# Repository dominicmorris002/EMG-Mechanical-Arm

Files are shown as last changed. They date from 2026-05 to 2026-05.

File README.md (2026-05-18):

# EMG Mechanical Arm

A myoelectric prosthetic arm that uses surface EMG signals to detect muscle gestures and drive a mechanical arm via a DC motor. The system consists of a **MyoWare 2.0 EMG sensor**, an **RP2040 microcontroller**, **DC motor driver H Bridge**, **Electrode Pads and Cable for Myoware Sensor**,  and a **DC motor** to control a 3D-printed mechanical arm.

---

## How It Works

The **RP2040** reads raw ADC values from the EMG sensor and uses the data to drive the H-Bridge to control the motor

---

## Repo Structure

```
EMG-Mechanical-Arm/
├── protomechanicalarm.py       # MicroPython code - Main product. Pre-tuned thresholds. Runs on RP2040 as main.py
├── learningarm.py              # MicroPython code - Optional. Adjusts thresholds automatically over time for better responsiveness
├── AITrainingCodeRP2040.py     # MicroPython code — runs on the RP2040 during AI data collection
├── AITrainingCodeComputer.py   # PC-side: collects data and trains the AI model
├── find_thresholds.py          # PC-side: finds ideal FLEX_ON / FLEX_OFF / FLEX_MAX thresholds
├── Doms PCB/                   # KiCad PCB design files
├── FinalPrint1/                # 3D print files (individual parts)
└── FULLPRINTFULLRightArm.3mf  # Full arm 3MF file for slicing
```

---

## Quickstart

You can choose to skip the AI thresholds and learning files as they work but are not needed for the product to run well. For the fastest and easiest approach plug in the PCB via USB to your computer.

1. **Download Thonny** and open `protomechanicalarm.py`
2. **Download MicroPython** onto the PCB through Thonny's interface at the bottom right — choose RP2040
3. **Save the file** by clicking File → Save As → MicroPython Device, and type `main.py`
4. The program will now always be stored on the chip and work as soon as plugged in

To change the trigger values of the sensor, simply change them in the code. The closer they are, the snappier they will be. Account for some amount of noise present. **14000 and 18000 are good starting numbers.**

---

## Optional: Learning Mode

If you want the arm to adapt and improve over time, use `learningarm.py` instead of `protomechanicalarm.py`. This version automatically adjusts the thresholds (`FLEX_ON`, `FLEX_OFF`, `FLEX_MAX`) based on your muscle signals during use. It learns from each flex/relax cycle and gets more responsive and personalized over time.

### How Learning Mode Works

- Tracks the peak muscle signal from each flex cycle
- Recalculates thresholds after each use based on a history of your last 10 peak signals
- Keeps thresholds within safe limits to prevent drift
- Prints threshold updates to the console so you can monitor adaptation

### When to Use Learning Mode

- You want the arm to automatically personalize to your muscle patterns
- You prefer not to manually tune threshold values
- You want the system to adapt to day-to-day variations in your signal

## Advanced: AI Training Mode

The AI training mode uses a Python script on your computer to collect muscle data and calculate optimal thresholds for you. This is optional and requires running Python scripts alongside the RP2040 code.

### Step 1 — Flash the RP2040 for Data Collection

Copy `AITrainingCodeRP2040.py` to your RP2040 as `main.py` using Thonny or `mpremote`. This streams raw ADC values over USB serial.

```python
# AITrainingCodeRP2040.py — runs on the RP2040
from machine import ADC, Pin
import time

adc = ADC(Pin(27))  # GP27 = ADC1

while True:
    val = adc.read_u16()  # 0–65535
    print(val)
    time.sleep_ms(1)      # ~1000 samples/sec
```

> **Important:** Close Thonny before running the PC training scripts. Both cannot hold the serial port at the same time.

---

### Step 2 — Install PC Dependencies

```bash
pip install numpy scipy pyserial tensorflow
```

---

### Step 3 — Collect EMG Data

```bash
python find_thresholds.py collect --label rest --port COM5 --seconds 20
python find_thresholds.py collect --label flex --port COM5 --seconds 20
```

Replace `COM5` with your actual serial port (`/dev/ttyACM0` on Linux/Mac).

---

### Step 4 — Process Windows

```bash
python find_thresholds.py windows
```

---

### Step 5 — Find Your Thresholds

```bash
python find_thresholds.py train_thresholds
```

This prints your personal `FLEX_ON`, `FLEX_OFF`, and `FLEX_MAX` values. Copy these into your motor control code on the RP2040.

---

## Bill of Materials (BOM)

> Costs omitted — use this as a copy-paste parts list for sourcing.

| Component | Description | Qty | Source / Part # |
|---|---|---|---|
| DC Motor | 12V High Torque Turbine Worm Geared Motor, 200 RPM, 8mm shaft | 1 | MECCANIXITY |
| Motor Driver | L298N Dual H-Bridge Motor Driver | 1 | Generic |
| EMG Sensor | MyoWare 2.0 compatible sensor cable | 1 | MyoWare |
| Electrode Pads | EMG Surface Electrodes, 6-pack | 3 packs | DigiKey #1528-2172-ND (Mfg #2773) |
| Microcontroller | RP2040 + PCB | 1 | Custom PCB via JLCPCB |
| Power Supply | 12V DC (5A) + 5V DC dual output power bank | 1 | ColdBye Dual Source Power Bank 12V and 5V |
| Enclosure | Custom 3D-printed enclosure | 1 | Print files in repo |
| Straps | Adjustable straps for arm attachment | 2 | Generic |
| Bearing (small) | 0.315" ID × 0.866" OD × 0.276" W | 15 | DigiKey #1995-1010-ND (Mfg #608-2RS-W/CHEVRONSRI2) |
| Bearing (large) | 0.591" ID × 1.26" OD × 0.354" W | 5 | DigiKey #1995-1014-ND (Mfg #6002ZZ) |
| Thread Inserts | 0.28" Dia × 0.38" H heat-set inserts | 50 | DigiKey #5519-HI-132-WH-ND (Mfg #HI-132-WH) |
| Machine Screws | Pan Phillips #10-32 | 50 | DigiKey #36-9909-ND (Mfg #9909) |
| Switches | SPST-NO 0.001A 5V detect switch | 50 | DigiKey #450-3349-ND (Mfg #JJOV0UL650NONPRBK) |
| PCBs | Custom arm PCBs assembled by JLCPCB | 1 | JLCPCB |
| Miscellaneous | Wires, breadboard, connectors | — | Generic |

---

## Hardware Notes

- EMG sensor connects to **GP27 (ADC1)** on the RP2040
- Motor driver IN1/IN2 pins connect to RP2040 GPIO outputs
- 12V powers the motor; RP2040 runs on 3.3V/5V USB — do not cross-connect
- Electrode placement: two signal electrodes along the muscle belly, one reference on a bony landmark (e.g., elbow)

---

## 3D Printing

The full arm model is included as `FULLPRINTFULLRightArm.3mf`. Individual parts are in the `FinalPrint1/` folder. Recommended print settings: H2D Printer Size with PLA Component.

---

## Project Gallery

<div align="center">

https://github.com/user-attachments/assets/b0d67ed7-32eb-4f09-bf58-b973187cbe4e

</div>

<div align="center">

Arm Assembly

</div>

<div align="center">

Full Arm Design

</div>

<div align="center">

Mechanical Detail

</div>

<div align="center">

Circuit Diagram

</div>

<div align="center">

System Overview

</div>

---

## License

### Custom License — EMG Mechanical Arm

**Copyright © 2026 Dominic Morris** — All Rights Reserved (unless specified below)

This project is shared under a **modified open-source license** with the following terms:

#### Permitted Uses:
- **Personal & Educational Use:** You may freely use, study, modify, and build upon this work for personal, non-commercial, and educational purposes.
- **Open Source Contributions:** You may fork, modify, and improve this project for non-commercial use.

#### Requirements:
- **Attribution Required:** You must credit Dominic Morris and link to this repository in any public use, distribution, or derived work.
- **Share Modifications:** Any modifications, improvements, or derivative works must be publicly shared (open-sourced) and made available to the community with attribution.
- **No Commercial Resale Without Permission:** You may NOT sell, commercialize, or profit from this work or any derivative without explicit written permission and a commercial licensing agreement.

#### Commercial Use:
- If you wish to commercialize this work (sell it as a product, include it in a commercial offering, or generate profit):
  1. You **must obtain explicit written permission** from Dominic Morris
  2. Dominic Morris **must receive credit** as the original creator
  3. Dominic Morris **must receive a fair share of profit** (terms to be negotiated)
  4. A formal licensing agreement must be established before commercialization

#### Disclaimer:
THIS PROJECT IS PROVIDED "AS IS" WITHOUT WARRANTY OF ANY KIND, EXPRESS OR IMPLIED. THE AUTHOR IS NOT LIABLE FOR ANY DAMAGES, INJURIES, OR LOSSES RESULTING FROM USE OF THIS PROJECT.

---

**For inquiries regarding commercial licensing, collaborations, or permission requests, please contact Dominic Morris.**

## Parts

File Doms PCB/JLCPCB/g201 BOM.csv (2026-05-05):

Reference | Value | Datasheet | Footprint | Qty | DNP
C1,C2,C9 | 100nF |  | Capacitor_SMD:C_0805_2012Metric | 3
C3,C5 | 15pF |  | Capacitor_SMD:C_0805_2012Metric | 2
C4,C6,C7,C8 | 10uF |  | Capacitor_SMD:C_0805_2012Metric | 4
D1 | D_Schottky_Small |  | Diode_SMD:D_SMA | 1
D2,D3,D4,D5 | LED |  | LED_SMD:LED_0805_2012Metric | 4
GPIOS1,H-Bridge1,H-Bridge2 | Conn_01x10 |  | Connector_PinHeader_2.54mm:PinHeader_1x10_P2.54mm_Vertical | 3
J1 | USB_C_Receptacle_USB2.0_16P | https://www.usb.org/sites/default/files/documents/usb_type-c.zip | Connector_USB:USB_C_Receptacle_HRO_TYPE-C-31-M-12 | 1
J2 | Conn_01x03 |  | Connector_PinSocket_2.54mm:PinSocket_1x03_P2.54mm_Vertical | 1
J3 | Conn_01x04 |  | Connector_PinSocket_2.54mm:PinSocket_1x04_P2.54mm_Vertical | 1
MyowareSensors1 | Conn_01x06 |  | Connector_PinHeader_2.54mm:PinHeader_1x06_P2.54mm_Vertical | 1
R1,R9,R10,R13,R14,R15 | 1k |  | Resistor_SMD:R_0805_2012Metric | 6
R2,R7 | 10k |  | Resistor_SMD:R_0805_2012Metric | 2
R3,R4 | 27 |  | Resistor_SMD:R_0805_2012Metric | 2
R5,R6 | 5.1K |  | Resistor_SMD:R_0805_2012Metric | 2
R8 | 100 |  | Resistor_SMD:R_0805_2012Metric | 1
R11,R12 | 4.7k |  | Resistor_SMD:R_0805_2012Metric | 2
R16 | 50 |  | Resistor_SMD:R_0805_2012Metric | 1
SW1 | SW_SPST |  | Button_Switch_SMD:SW_SPST_CK_RS282G05A3 | 1
U1 | W25Q32JVSS | http://www.winbond.com/resource-files/w25q32jv%20revg%2003272018%20plus.pdf | Package_SO:SOIC-8_5.23x5.23mm_P1.27mm | 1
U2 | AMS1117-3.3 | http://www.advanced-monolithic.com/pdf/ds1117.pdf | Package_TO_SOT_SMD:SOT-223-3_TabPin2 | 1
U3 | RP2040 | https://datasheets.raspberrypi.com/rp2040/rp2040-datasheet.pdf | Package_DFN_QFN:QFN-56-1EP_7x7mm_P0.4mm_EP3.2x3.2mm | 1
Y1 | 12Mhz |  | Crystal:Crystal_SMD_SeikoEpson_FA238V-4Pin_3.2x2.5mm | 1

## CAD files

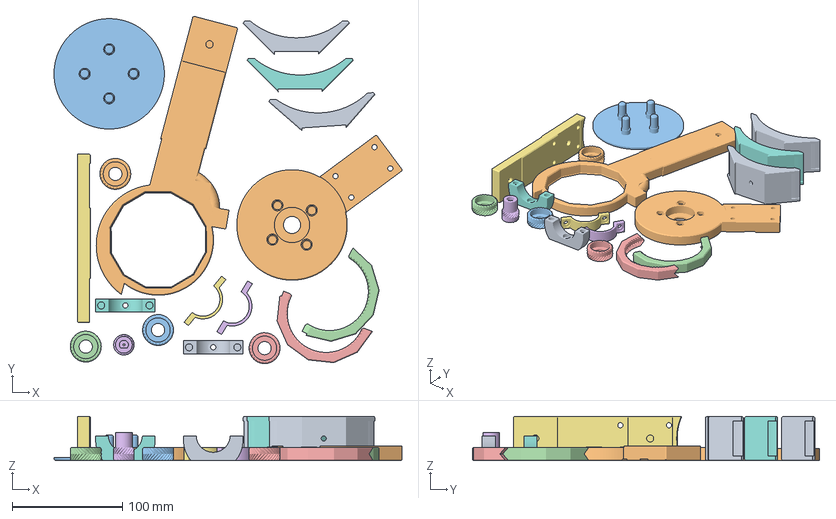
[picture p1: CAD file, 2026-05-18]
FULLPRINTFULLRightArm.3mf
315.3 x 314.7 x 40.0 mm
armBracket2.stl x 3
UpperArmT.stl
coverPlate.stl
prOutside.stl x 2
motorClampUpper.stl x 2
motorClampLower.stl x 2
planetGear.stl x 4
prSunGear.stl
upperArmB2.stl
Assembly_B_B

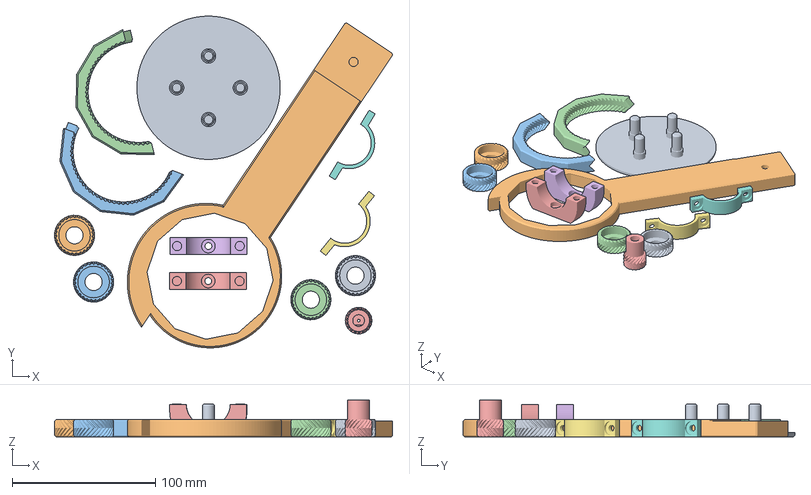
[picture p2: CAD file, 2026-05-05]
FinalPrint1/fullPlatePrintPart1.3mf
235.9 x 231.6 x 25.5 mm
coverPlate.stl
lowerArm.stl
prOutside.stl x 2
motorClampLower.stl x 2
motorClampUpper.stl x 2
planetGear.stl x 4
prSunGear.stl

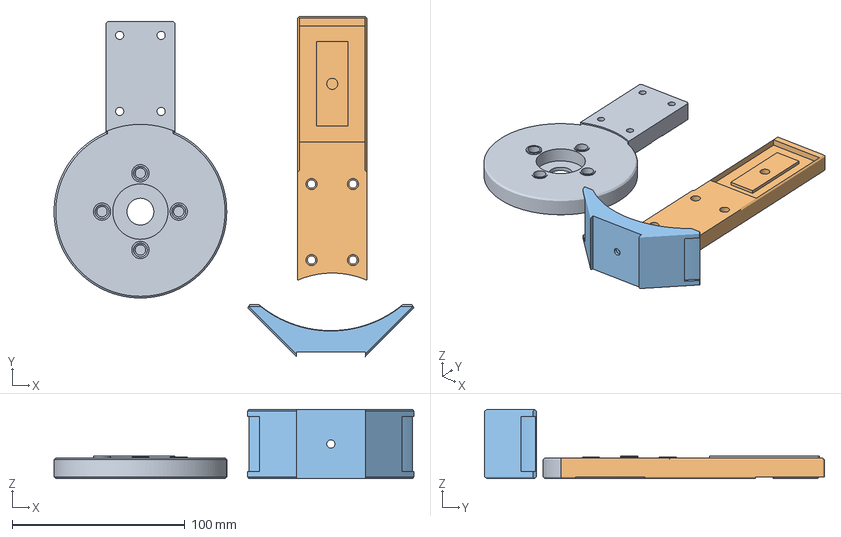
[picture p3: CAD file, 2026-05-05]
FinalPrint1/fullPlatePrintPart2.3mf
208.3 x 196.8 x 40.0 mm
UpperArmT.stl
upperArmB2.stl
armBracket2.stl

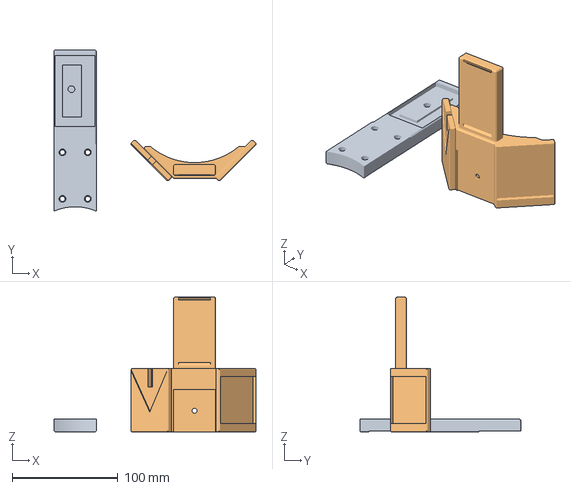
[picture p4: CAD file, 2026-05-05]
FinalPrint1/coverPlate.3mf
191.1 x 152.6 x 127.5 mm
upperArmB2.stl
customBracket.stl

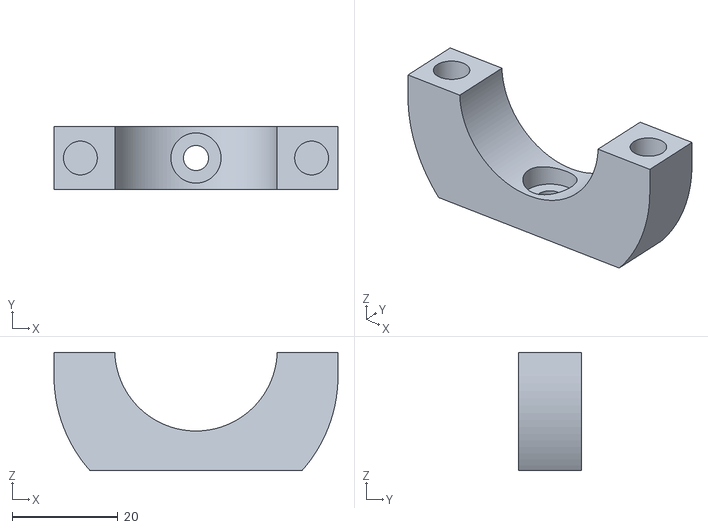
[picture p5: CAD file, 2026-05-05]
FinalPrint1/motorClampLower.stl
53.8 x 12.0 x 22.4

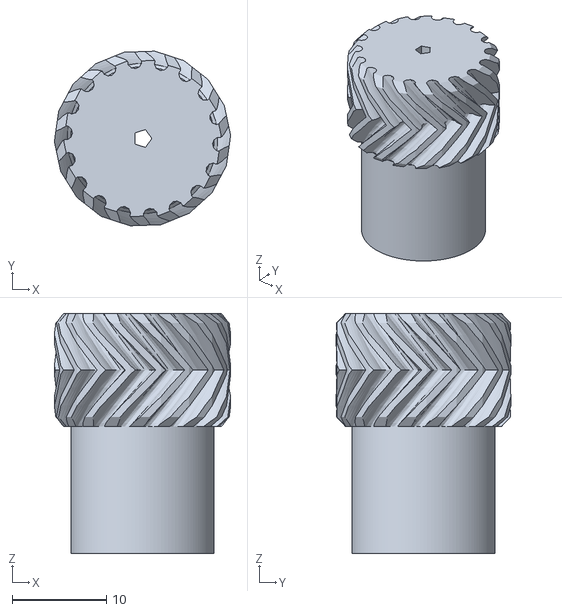
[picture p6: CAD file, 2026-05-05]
FinalPrint1/prSunGear.stl
18.7 x 18.6 x 25.5

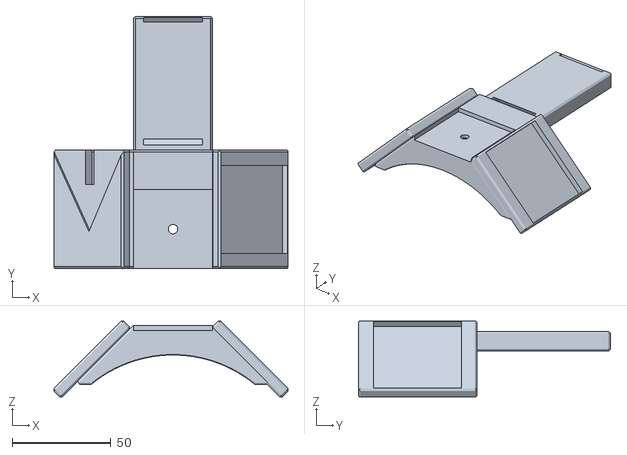
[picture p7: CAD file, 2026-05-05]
FinalPrint1/customBracket.stl
118.2 x 127.5 x 38.2

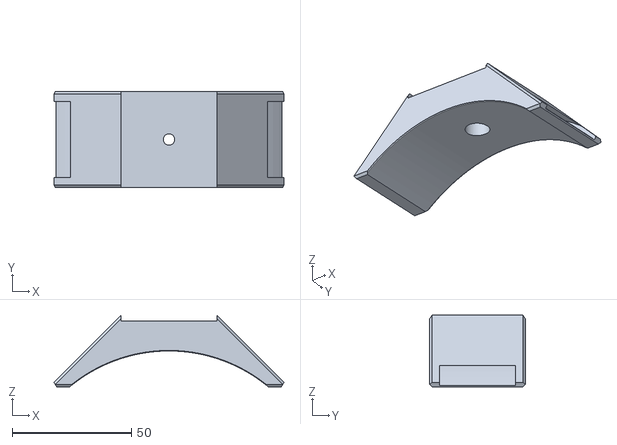
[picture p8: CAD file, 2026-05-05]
FinalPrint1/armBracket2.stl
96.2 x 40.0 x 30.0

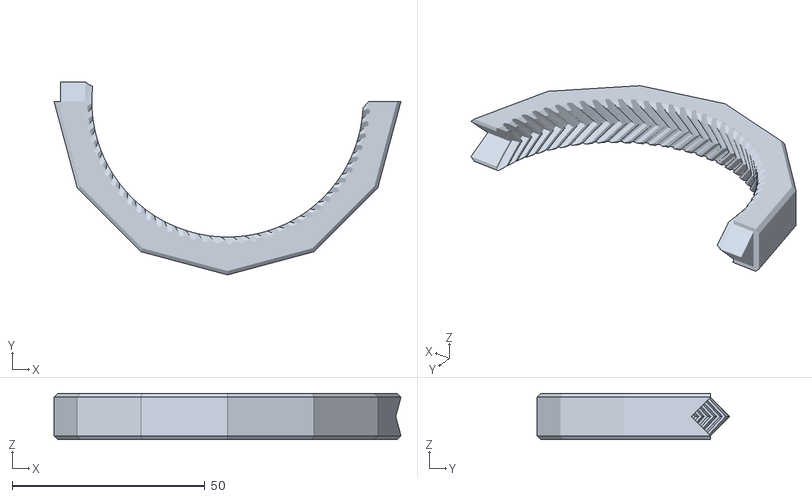
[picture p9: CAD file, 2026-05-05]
FinalPrint1/prOutside.stl
90.0 x 50.0 x 12.0

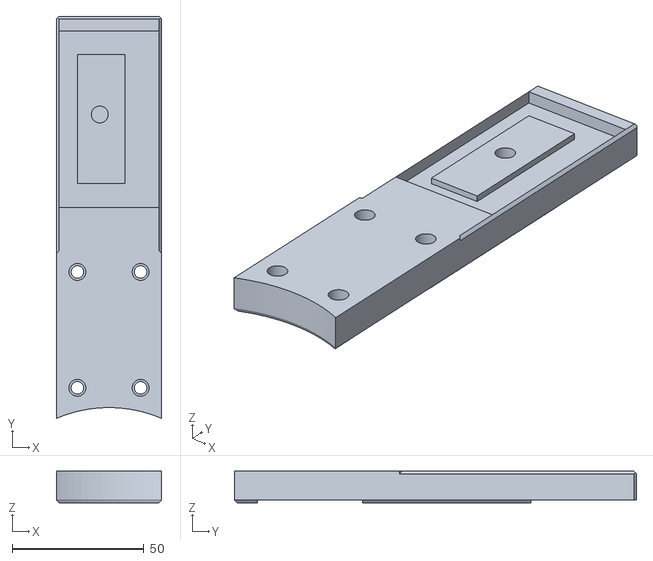
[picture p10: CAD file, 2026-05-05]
FinalPrint1/upperArmB2.stl
40.0 x 152.6 x 12.0

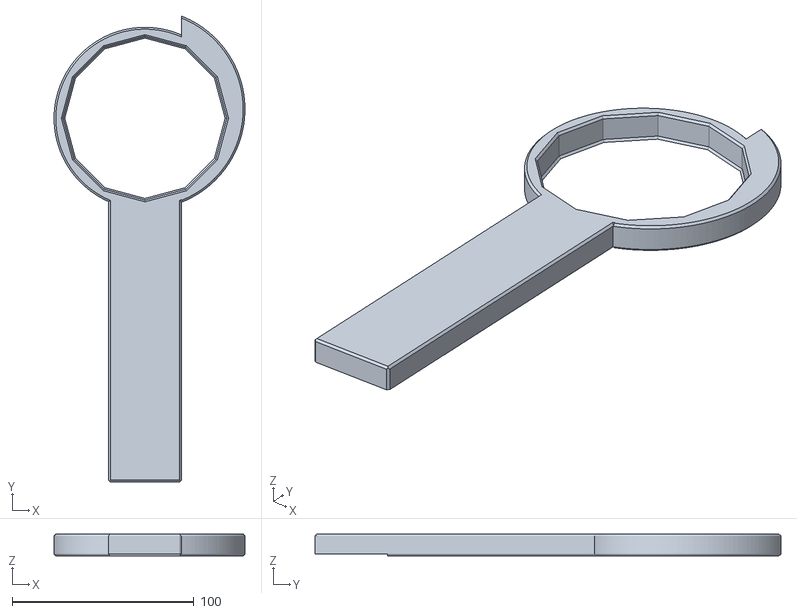
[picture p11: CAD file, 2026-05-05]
FinalPrint1/lowerArm.stl
105.0 x 256.2 x 12.0

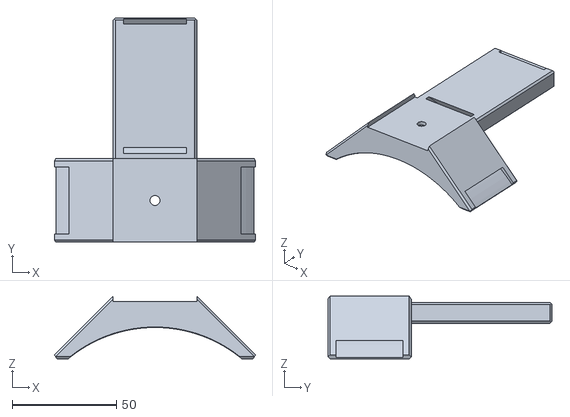
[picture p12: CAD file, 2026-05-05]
FinalPrint1/strapSupporBatt.stl
96.2 x 107.5 x 30.0

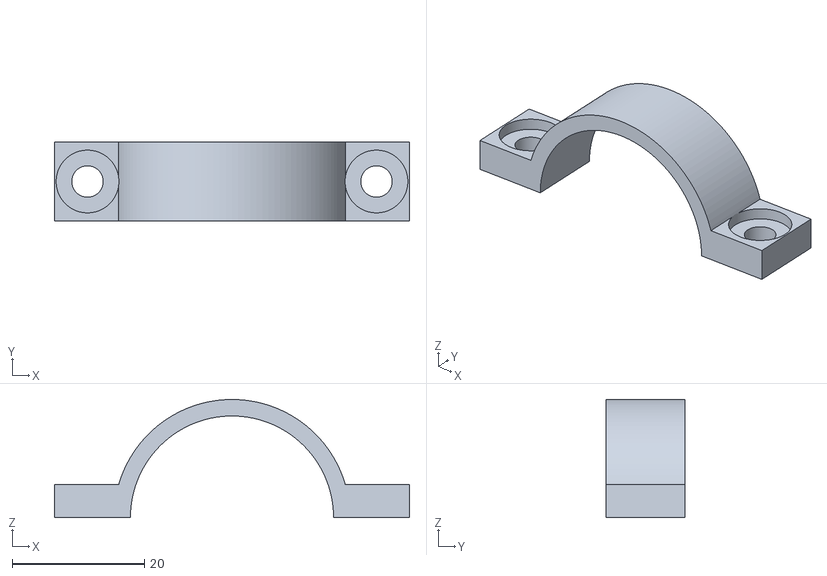
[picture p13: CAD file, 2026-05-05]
FinalPrint1/motorClampUpper.stl
53.8 x 12.0 x 17.9

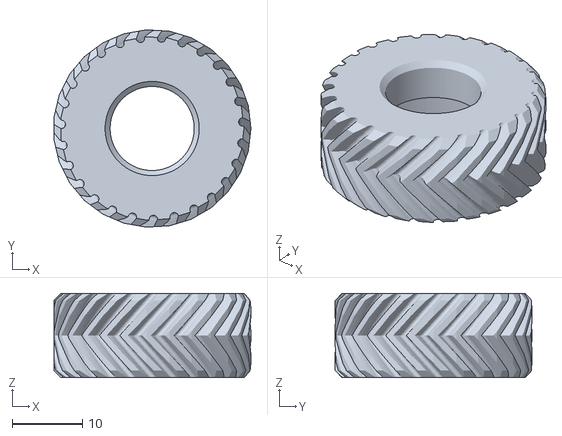
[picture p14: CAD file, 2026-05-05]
FinalPrint1/planetGear.stl
28.0 x 28.1 x 12.0

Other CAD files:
FinalPrint1/meshCover.stl
FinalPrint1/UpperArmT.stl
FinalPrint1/coverPlate.stl

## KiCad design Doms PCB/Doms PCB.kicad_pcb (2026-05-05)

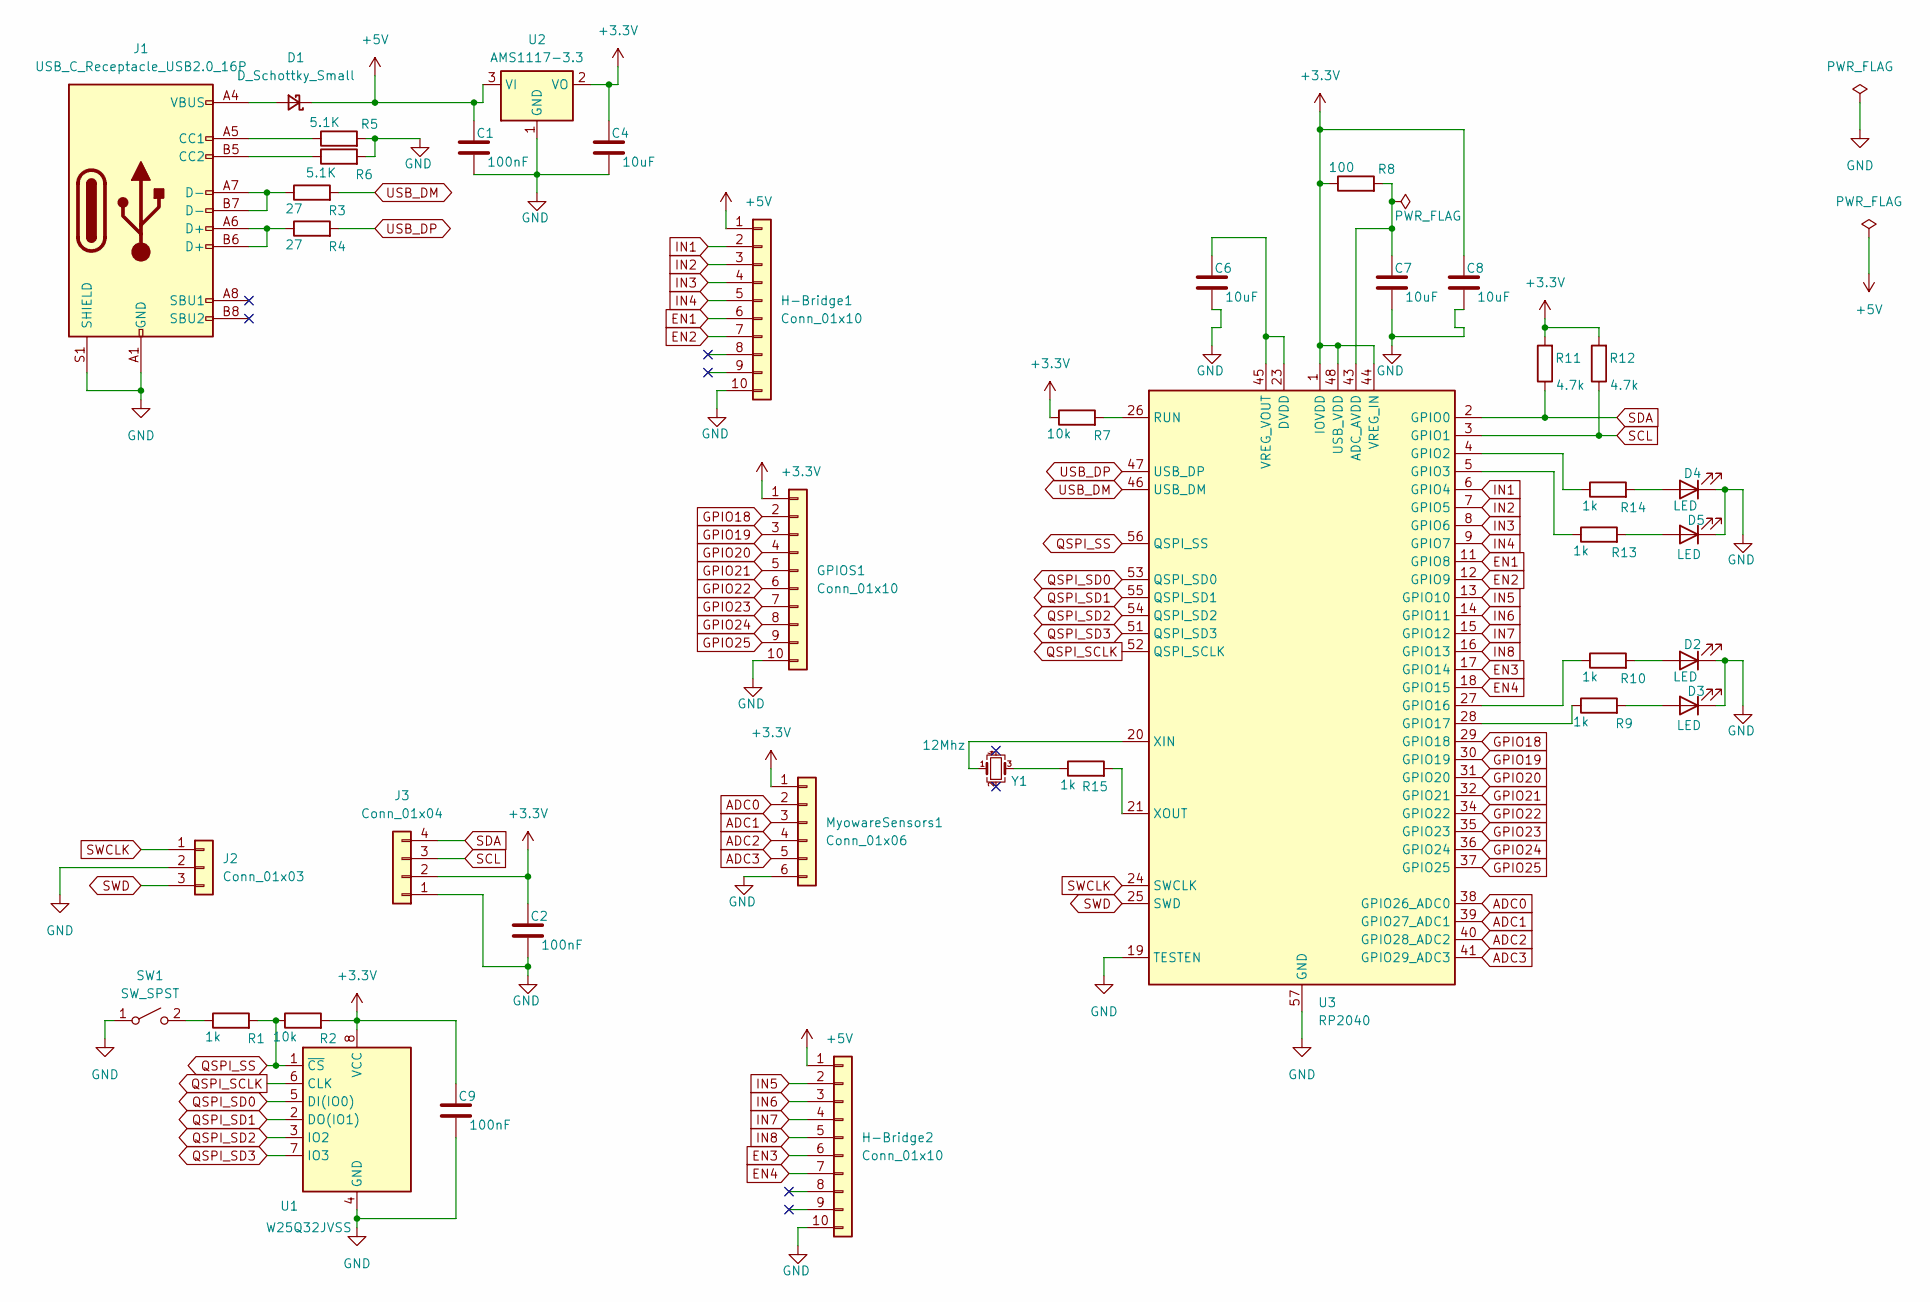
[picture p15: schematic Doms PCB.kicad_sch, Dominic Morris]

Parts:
C1, C2, C9: 100nF; C_0805_2012Metric
C4, C6, C7, C8: 10uF; C_0805_2012Metric
D1: D_Schottky_Small; D_SMA
D2, D3, D4, D5: LED; LED_0805_2012Metric
GPIOS1: Conn_01x10; PinHeader_1x10_P2.54mm_Vertical
H-Bridge1, H-Bridge2: Conn_01x10; PinHeader_1x10_P2.54mm_Vertical
J1: USB_C_Receptacle_USB2.0_16P; USB_C_Receptacle_HRO_TYPE-C-31-M-12
J2: Conn_01x03; PinSocket_1x03_P2.54mm_Vertical
J3: Conn_01x04; PinSocket_1x04_P2.54mm_Vertical
MyowareSensors1: Conn_01x06; PinHeader_1x06_P2.54mm_Vertical
R1, R9, R10, R13, R14, R15: 1k; R_0805_2012Metric
R2, R7: 10k; R_0805_2012Metric
R3, R4: 27; R_0805_2012Metric
R5, R6: 5.1K; R_0805_2012Metric
R8: 100; R_0805_2012Metric
R11, R12: 4.7k; R_0805_2012Metric
SW1: SW_SPST; SW_SPST_CK_RS282G05A3
U1: W25Q32JVSS; SOIC-8_5.23x5.23mm_P1.27mm
U2: AMS1117-3.3; SOT-223-3_TabPin2
U3: RP2040; QFN-56-1EP_7x7mm_P0.4mm_EP3.2x3.2mm
Y1: 12Mhz; Crystal_SMD_SeikoEpson_FA238V-4Pin_3.2x2.5mm

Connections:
+3.3V: C2.1, C4.1, C8.1, C9.1, GPIOS1.1, J3.2, MyowareSensors1.1, R2.2, R7.1, R8.1, R11.2, R12.2, U1.8 (VCC), U2.2 (VO), U3.1 (IOVDD), U3.10 (IOVDD), U3.22 (IOVDD), U3.33 (IOVDD), U3.42 (IOVDD), U3.44 (VREG_IN), U3.48 (USB_VDD), U3.49 (IOVDD)
+5V: C1.1, D1.1 (K), H-Bridge1.1, H-Bridge2.1, U2.3 (VI)
ADC0: MyowareSensors1.2, U3.38 (GPIO26_ADC0)
ADC1: MyowareSensors1.3, U3.39 (GPIO27_ADC1)
ADC2: MyowareSensors1.4, U3.40 (GPIO28_ADC2)
ADC3: MyowareSensors1.5, U3.41 (GPIO29_ADC3)
EN1: H-Bridge1.6, U3.11 (GPIO8)
EN2: H-Bridge1.7, U3.12 (GPIO9)
EN3: H-Bridge2.6, U3.17 (GPIO14)
EN4: H-Bridge2.7, U3.18 (GPIO15)
GND: C1.2, C2.2, C4.2, C6.2, C7.2, C8.2, C9.2, D2.1 (K), D3.1 (K), D4.1 (K), D5.1 (K), GPIOS1.10, H-Bridge1.10, H-Bridge2.10, J1.A1 (GND), J1.A12 (GND), J1.B1 (GND), J1.B12 (GND), J1.S1 (SHIELD), J2.2, J3.1, MyowareSensors1.6, R5.2, R6.2, SW1.1 (A), U1.4 (GND), U2.1 (GND), U3.19 (TESTEN), U3.57 (GND)
GPIO18: GPIOS1.2, U3.29 (GPIO18)
GPIO19: GPIOS1.3, U3.30 (GPIO19)
GPIO20: GPIOS1.4, U3.31 (GPIO20)
GPIO21: GPIOS1.5, U3.32 (GPIO21)
GPIO22: GPIOS1.6, U3.34 (GPIO22)
GPIO23: GPIOS1.7, U3.35 (GPIO23)
GPIO24: GPIOS1.8, U3.36 (GPIO24)
GPIO25: GPIOS1.9, U3.37 (GPIO25)
IN1: H-Bridge1.2, U3.6 (GPIO4)
IN2: H-Bridge1.3, U3.7 (GPIO5)
IN3: H-Bridge1.4, U3.8 (GPIO6)
IN4: H-Bridge1.5, U3.9 (GPIO7)
IN5: H-Bridge2.2, U3.13 (GPIO10)
IN6: H-Bridge2.3, U3.14 (GPIO11)
IN7: H-Bridge2.4, U3.15 (GPIO12)
IN8: H-Bridge2.5, U3.16 (GPIO13)
unnamed: D1.2 (A), J1.A4 (VBUS), J1.A9 (VBUS), J1.B4 (VBUS), J1.B9 (VBUS)
unnamed: D2.2 (A), R10.2
unnamed: D3.2 (A), R9.2
unnamed: D4.2 (A), R14.2
unnamed: D5.2 (A), R13.2
unnamed: J1.A5 (CC1), R5.1
unnamed: J1.B5 (CC2), R6.1
unnamed: J1.A6 (D+), J1.B6 (D+), R4.1
unnamed: J1.A7 (D-), J1.B7 (D-), R3.1
unnamed: R15.1, Y1.3
unnamed: R1.1, SW1.2 (B)
unnamed: C7.1, R8.2, U3.43 (ADC_AVDD)
unnamed: R14.1, U3.4 (GPIO2)
unnamed: R13.1, U3.5 (GPIO3)
unnamed: R10.1, U3.27 (GPIO16)
unnamed: R9.1, U3.28 (GPIO17)
unnamed: R7.2, U3.26 (RUN)
unnamed: C6.1, U3.23 (DVDD), U3.45 (VREG_VOUT), U3.50 (DVDD)
unnamed: U3.20 (XIN), Y1.1
unnamed: R15.2, U3.21 (XOUT)
QSPI_SCLK: U1.6 (CLK), U3.52 (QSPI_SCLK)
QSPI_SD0: U1.5 (DI(IO0)), U3.53 (QSPI_SD0)
QSPI_SD1: U1.2 (DO(IO1)), U3.55 (QSPI_SD1)
QSPI_SD2: U1.3 (IO2), U3.54 (QSPI_SD2)
QSPI_SD3: U1.7 (IO3), U3.51 (QSPI_SD3)
QSPI_SS: R1.2, R2.1, U1.1 (~CS), U3.56 (QSPI_SS)
SCL: J3.3, R12.1, U3.3 (GPIO1)
SDA: J3.4, R11.1, U3.2 (GPIO0)
SWCLK: J2.1, U3.24 (SWCLK)
SWD: J2.3, U3.25 (SWD)
USB_DM: R3.2, U3.46 (USB_DM)
USB_DP: R4.2, U3.47 (USB_DP)

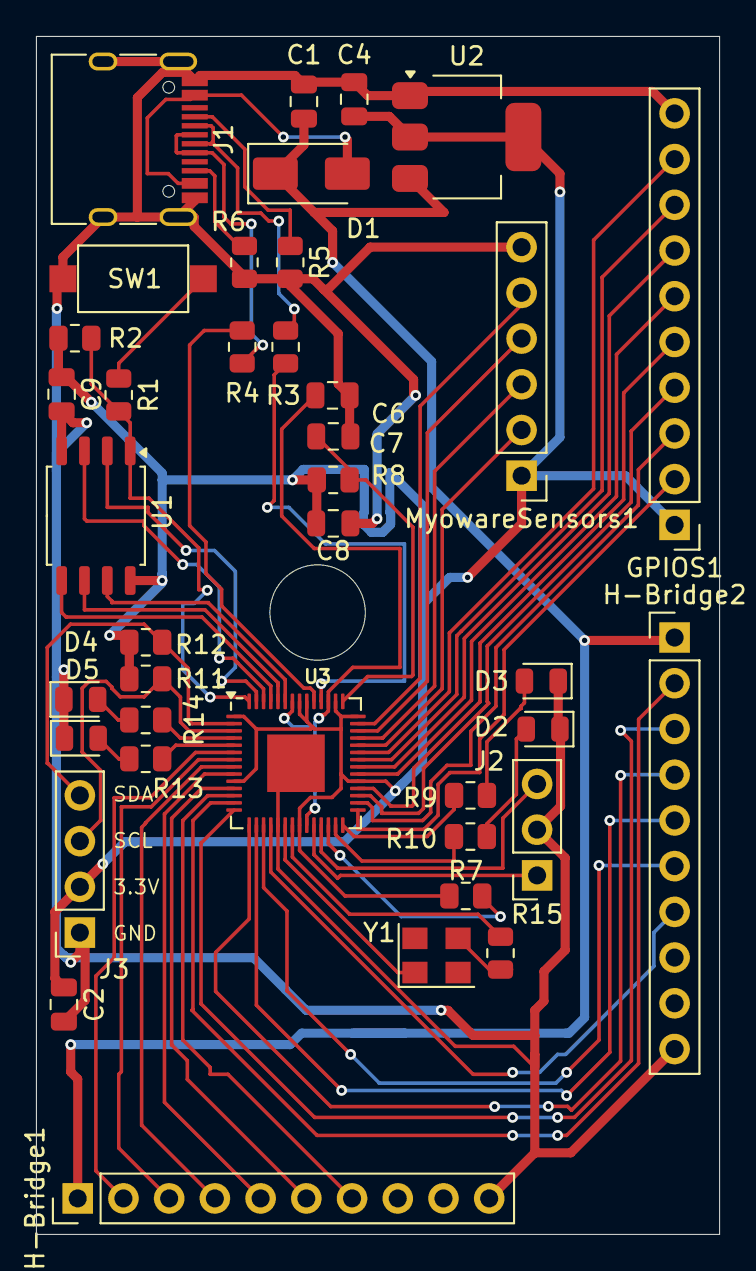
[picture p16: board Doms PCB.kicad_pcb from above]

Board: 2 copper layers, 38.0 x 66.6 mm, 39 parts (0 on the bottom side), 59 nets.

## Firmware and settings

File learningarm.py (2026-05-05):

from machine import Pin, ADC, PWM
import time

# --- Sensor ---
adc = ADC(Pin(27))

# --- H-Bridge pins ---
in1 = Pin(4, Pin.OUT); in2 = Pin(5, Pin.OUT)
en1 = PWM(Pin(8)); en1.freq(20000)

# --- LEDs ---
leds = [Pin(2, Pin.OUT), Pin(3, Pin.OUT), Pin(16, Pin.OUT), Pin(17, Pin.OUT)]

# --- Motor ---
def motor_forward(speed):
    in1.value(1); in2.value(0)
    en1.duty_u16(int(65535 * speed))
def motor_reverse(speed):
    in1.value(0); in2.value(1)
    en1.duty_u16(int(65535 * speed))
def motor_stop():
    in1.value(0); in2.value(0)
    en1.duty_u16(0)

# --- Rolling average ---
WINDOW = 20
readings = [0] * WINDOW
read_idx = 0
def smoothed_read():
    global read_idx
    val = adc.read_u16()
    readings[read_idx] = val
    read_idx = (read_idx + 1) % WINDOW
    return sum(readings) // WINDOW

# ============================================================
# --- Adaptive Smart Thresholds ---
# Tuned for: resting signal ~14500, peaks hitting 65535
#
# Signal zones:
#   ~14500  = fully relaxed (idle)
#   15200   = FLEX_OFF — just above idle, easy to drop below when relaxing
#   20971   = FLEX_ON  — clear activation point
#   60000+  = full flex
# ============================================================
FLEX_ON  = 20000
FLEX_OFF = 15200   # tight above idle ~14500 — relaxing easily clears this
FLEX_MAX = 60000

MIN_SPEED = 0.15
MAX_SPEED = 0.90

# Adaptive ratios
ON_RATIO       = 0.32
OFF_RATIO      = 0.24   # tracks just above idle fraction of avg peak
MAX_LEARN_RATE = 0.10

# Peak history
PEAK_HISTORY  = 10
best_peak     = FLEX_MAX
session_peaks = []

# Clamp limits — OFF kept tight above idle band
FLEX_ON_MIN  = 17000; FLEX_ON_MAX  = 40000
FLEX_OFF_MIN = 14800; FLEX_OFF_MAX = 18000  # never stray far from idle+700
FLEX_MAX_MIN = 40000; FLEX_MAX_MAX = 65000

flex_peak_this_rep = 0

def update_adaptive_thresholds(peak):
    global FLEX_ON, FLEX_OFF, FLEX_MAX, best_peak, session_peaks

    if peak < FLEX_ON:
        return  # ignore junk reps

    if peak > best_peak:
        best_peak = peak
        print("[Adaptive] New best peak: {}".format(best_peak))

    session_peaks.append(peak)
    if len(session_peaks) > PEAK_HISTORY:
        session_peaks.pop(0)

    avg_peak = sum(session_peaks) // len(session_peaks)

    new_on  = int(avg_peak * ON_RATIO)
    new_off = int(avg_peak * OFF_RATIO)
    new_max = int(FLEX_MAX + MAX_LEARN_RATE * (best_peak - FLEX_MAX))

    FLEX_ON  = max(FLEX_ON_MIN,  min(new_on,  FLEX_ON_MAX))
    FLEX_OFF = max(FLEX_OFF_MIN, min(new_off, FLEX_OFF_MAX))
    FLEX_MAX = max(FLEX_MAX_MIN, min(new_max, FLEX_MAX_MAX))

    # Enforce gap: OFF must always be below ON with room to spare
    if FLEX_OFF >= FLEX_ON - 2000:
        FLEX_OFF = FLEX_ON - 2500

    print("[Adaptive] ON:{} OFF:{} MAX:{} (avg_peak:{} best:{})".format(
        FLEX_ON, FLEX_OFF, FLEX_MAX, avg_peak, best_peak))

# ============================================================

# --- Timing ---
DEBOUNCE_MS = 150   # hold above FLEX_ON this long to activate
RELEASE_MS  = 120   # hold below FLEX_OFF this long to stop
GUARD_MS    = 500   # min gap between stop and next activation

# --- State ---
flex_above_since   = None
flex_below_since   = None
last_stop          = -9999
is_flexing         = False
direction          = "FORWARD"
current_speed      = 0.0
RAMP_STEP          = 0.03

def ramp_speed(target):
    global current_speed
    if target > current_speed:
        current_speed = min(current_speed + RAMP_STEP, target)
    else:
        current_speed = max(current_speed - RAMP_STEP, target)
    return current_speed

def muscle_to_speed(muscle):
    clamped = max(FLEX_ON, min(muscle, FLEX_MAX))
    t = (clamped - FLEX_ON) / max(1, (FLEX_MAX - FLEX_ON))
    return MIN_SPEED + t * (MAX_SPEED - MIN_SPEED)

# Seed rolling buffer
for _ in range(WINDOW):
    smoothed_read()

# --- LED ---
led_pattern   = [(1,0,0,0),(1,1,0,0),(1,1,1,0),(1,1,1,1),(0,0,0,0)]
led_step      = 0
led_interval  = 300
last_led_time = time.ticks_ms()

print_interval  = 200
last_print_time = time.ticks_ms()

print("Ready!")
print("Thresholds | ON:{} OFF:{} MAX:{}  DEBOUNCE:{}ms RELEASE:{}ms".format(
    FLEX_ON, FLEX_OFF, FLEX_MAX, DEBOUNCE_MS, RELEASE_MS))
print("Idle should read BELOW OFF:{}".format(FLEX_OFF))

while True:
    now    = time.ticks_ms()
    muscle = smoothed_read()

    # --- LED pattern ---
    if time.ticks_diff(now, last_led_time) >= led_interval:
        p = led_pattern[led_step]
        for i, led in enumerate(leds):
            led.value(p[i])
        led_step = (led_step + 1) % len(led_pattern)
        last_led_time = now

    # -------------------------------------------------------
    # NOT flexing — watch for activation
    # -------------------------------------------------------
    if not is_flexing:
        if muscle >= FLEX_ON:
            if flex_above_since is None:
                flex_above_since = now
            elif (time.ticks_diff(now, flex_above_since) >= DEBOUNCE_MS
                  and time.ticks_diff(now, last_stop) >= GUARD_MS):
                is_flexing         = True
                current_speed      = 0.0
                flex_peak_this_rep = muscle
                flex_above_since   = None
                flex_below_since   = None
                print("Flex -> {}".format(direction))
        else:
            flex_above_since = None

    # -------------------------------------------------------
    # IS flexing — drive motor, watch for release
    # -------------------------------------------------------
    if is_flexing:
        if muscle >= FLEX_OFF:
            # Signal healthy — keep driving, reset release timer
            flex_below_since = None

            if muscle > flex_peak_this_rep:
                flex_peak_this_rep = muscle

            speed = ramp_speed(muscle_to_speed(muscle))
            if direction == "FORWARD":
                motor_forward(speed)
            else:
                motor_reverse(speed)

        else:
            # Signal dropped below OFF — start release timer
            if flex_below_since is None:
                flex_below_since = now
            elif time.ticks_diff(now, flex_below_since) >= RELEASE_MS:
                # Held low long enough — genuine relax
                is_flexing    = False
                current_speed = 0.0
                motor_stop()
                last_stop        = now
                flex_below_since = None
                flex_above_since = None

                update_adaptive_thresholds(flex_peak_this_rep)
                flex_peak_this_rep = 0

                direction = "REVERSE" if direction == "FORWARD" else "FORWARD"
                print("Relax -> STOP  (next: {})".format(direction))

    # -------------------------------------------------------
    # Print
    # -------------------------------------------------------
    if time.ticks_diff(now, last_print_time) >= print_interval:
        if is_flexing:
            print("Sensor:{}  {}  speed:{:.0f}%  target:{:.0f}%  peak:{}  OFF:{}".format(
                muscle, direction,
                current_speed * 100,
                muscle_to_speed(muscle) * 100,
                flex_peak_this_rep,
                FLEX_OFF))
        else:
            print("Idle | sensor:{}  ON:{}  OFF:{}".format(muscle, FLEX_ON, FLEX_OFF))
        last_print_time = now

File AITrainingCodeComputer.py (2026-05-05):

#!/usr/bin/env python3
"""
STEP2_train_and_export.py
=========================

Runs on your PC. Does 5 things:
  1) collect          — record EMG gestures to CSV
  2) windows          — slice CSVs into training windows
  3) train            — train CNN gesture classifier
  4) export_uc        — export CNN weights for RP2040
  5) train_thresholds — train AI to learn FLEX thresholds

"""

import argparse, csv, json, time
from pathlib import Path
from collections import Counter
import numpy as np
from scipy.signal import butter, lfilter, iirnotch

try:
    import serial
except ImportError:
    serial = None

try:
    import tensorflow as tf
except ImportError:
    tf = None

# ───────────────────────── Config ─────────────────────────
FS       = 1000
WIN      = 128
OVERLAP  = 0.5
BP_LOW   = 20.0
BP_HIGH  = 450.0
NOTCH    = 60.0
ENV_LP   = 10.0

RAW_DIR  = Path("data/raw")
PROC_DIR = Path("data/processed")
MDL_DIR  = Path("models")

CLASSES  = ["rest", "flex", "extend", "grip_close", "grip_open"]

# ───────────────────────── DSP ─────────────────────────────
def _butter_bp(x, fs, lo, hi, order=4):
    nyq = 0.5 * fs
    b, a = butter(order, [lo/nyq, hi/nyq], btype='band')
    return lfilter(b, a, x)

def _notch(x, fs, f0=60.0, Q=30.0):
    if f0 <= 0: return x
    b, a = iirnotch(f0, Q, fs)
    return lfilter(b, a, x)

def _lp(x, fs, cutoff, order=4):
    nyq = 0.5 * fs
    b, a = butter(order, cutoff/nyq, btype='low')
    return lfilter(b, a, x)

def preprocess(x, fs=FS):
    x = _butter_bp(x, fs, BP_LOW, BP_HIGH)
    x = _notch(x, fs, NOTCH)
    x = np.abs(x)
    x = _lp(x, fs, ENV_LP)
    return x

# ───────────────────────── Helpers ─────────────────────────
def window_array(x, win, step):
    idx = range(0, len(x) - win + 1, step)
    return np.stack([x[s:s+win] for s in idx], 0) if len(list(range(0, len(x)-win+1, step))) else np.zeros((0, win))

def ensure_dirs():
    for d in [RAW_DIR, PROC_DIR, MDL_DIR]:
        d.mkdir(parents=True, exist_ok=True)

# ───────────────────────── 1. Collect ──────────────────────
def cmd_collect(args):
    if serial is None:
        raise SystemExit("pip install pyserial")
    ensure_dirs()

    fname = RAW_DIR / f"{int(time.time())}_{args.label}.csv"

    print(f"\n[collect] {args.label} for {args.seconds}s")
    time.sleep(3)

    ser = serial.Serial(args.port, baudrate=115200, timeout=1)
    t_end = time.time() + args.seconds

    with open(fname, 'w', newline='') as f:
        w = csv.writer(f)
        w.writerow(['emg', 'label'])
        while time.time() < t_end:
            line = ser.readline().decode(errors='ignore').strip()
            try:
                val = int(line)
                w.writerow([val, args.label])
            except:
                continue

    ser.close()
    print(f"[collect] saved → {fname}")

# ───────────────────────── 2. Windows ──────────────────────
def cmd_windows(args):
    ensure_dirs()
    step = int(WIN * (1 - OVERLAP))

    X_list, y_list = [], []

    for csvp in RAW_DIR.glob("*.csv"):
        label = csvp.stem.split("_")[-1]
        raw = np.loadtxt(csvp, delimiter=",", skiprows=1, usecols=(0,))
        env = preprocess(raw)
        W = window_array(env, WIN, step)

        if len(W) == 0: continue

        X_list.append(W)
        y_list.append(np.array([label]*len(W)))

    X = np.concatenate(X_list)[:, :, None]
    y = np.concatenate(y_list)

    np.save(PROC_DIR / "X.npy", X)
    np.save(PROC_DIR / "y.npy", y)

    print(f"[windows] X{X.shape} saved")

# ───────────────────────── 3. CNN Train ────────────────────
def build_model(win, n_classes):
    i = tf.keras.Input(shape=(win,1))
    x = tf.keras.layers.Conv1D(8,7,activation='relu',padding='same')(i)
    x = tf.keras.layers.MaxPool1D(2)(x)
    x = tf.keras.layers.Conv1D(16,5,activation='relu',padding='same')(x)
    x = tf.keras.layers.GlobalAveragePooling1D()(x)
    o = tf.keras.layers.Dense(n_classes,activation='softmax')(x)

    m = tf.keras.Model(i,o)
    m.compile(optimizer='adam',loss='sparse_categorical_crossentropy',metrics=['accuracy'])
    return m

def cmd_train(args):
    X = np.load(PROC_DIR/"X.npy")
    y_str = np.load(PROC_DIR/"y.npy",allow_pickle=True)

    labels = sorted(set(y_str))
    lab2id = {l:i for i,l in enumerate(labels)}
    y = np.array([lab2id[v] for v in y_str])

    model = build_model(WIN,len(labels))
    model.fit(X,y,epochs=args.epochs,batch_size=64)

    model.save(MDL_DIR/"emg_savedmodel")
    print("[train] done")

# ───────────────────────── 4. Threshold AI ─────────────────
def extract_features(X):
    X = X.squeeze(-1)
    return np.stack([
        X.mean(axis=1),
        X.std(axis=1),
        X.max(axis=1),
        np.sqrt((X**2).mean(axis=1))
    ], axis=1)

def generate_targets(X,y):
    Xf = extract_features(X)

    rest = Xf[y=="rest"]
    flex = Xf[y=="flex"]

    mu = rest[:,0].mean()
    std = rest[:,1].mean()

    FLEX_ON  = mu + 3*std
    FLEX_OFF = mu + 1.5*std
    FLEX_MAX = np.percentile(flex[:,2],95)

    return Xf, np.tile([FLEX_ON,FLEX_OFF,FLEX_MAX],(len(Xf),1))

def cmd_train_thresholds(args):
    X = np.load(PROC_DIR/"X.npy")
    y = np.load(PROC_DIR/"y.npy",allow_pickle=True)

    Xf, targets = generate_targets(X,y)

    model = tf.keras.Sequential([
        tf.keras.layers.Dense(16,activation='relu',input_shape=(4,)),
        tf.keras.layers.Dense(16,activation='relu'),
        tf.keras.layers.Dense(3)
    ])

    model.compile(optimizer='adam',loss='mse')
    model.fit(Xf,targets,epochs=40)

    preds = model.predict(Xf)
    FLEX_ON,FLEX_OFF,FLEX_MAX = preds.mean(axis=0)

    FLEX_ON  = int(FLEX_ON)
    FLEX_OFF = int(FLEX_OFF)
    FLEX_MAX = int(FLEX_MAX)

    print("\n=== AI THRESHOLDS ===")
    print(FLEX_ON,FLEX_OFF,FLEX_MAX)

    (MDL_DIR/"thresholds.json").write_text(json.dumps({
        "FLEX_ON":FLEX_ON,
        "FLEX_OFF":FLEX_OFF,
        "FLEX_MAX":FLEX_MAX
    },indent=2))

# ───────────────────────── CLI ─────────────────────────────
if __name__ == "__main__":
    p = argparse.ArgumentParser()
    sub = p.add_subparsers(dest="cmd",required=True)

    pc = sub.add_parser("collect")
    pc.add_argument("--label",required=True,choices=CLASSES)
    pc.add_argument("--seconds",type=int,default=20)
    pc.add_argument("--port",required=True)
    pc.set_defaults(func=cmd_collect)

    sub.add_parser("windows").set_defaults(func=cmd_windows)

    pt = sub.add_parser("train")
    pt.add_argument("--epochs",type=int,default=30)
    pt.set_defaults(func=cmd_train)

    sub.add_parser("train_thresholds").set_defaults(func=cmd_train_thresholds)

    args = p.parse_args()
    args.func(args)


"""
==================== HOW TO USE ====================

1. Install dependencies:
   pip install numpy scipy pyserial tensorflow

2. Collect data:
   python STEP2_train_and_export.py collect --label rest --port COM5
   python STEP2_train_and_export.py collect --label flex --port COM5

3. Process data:
   python STEP2_train_and_export.py windows
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
